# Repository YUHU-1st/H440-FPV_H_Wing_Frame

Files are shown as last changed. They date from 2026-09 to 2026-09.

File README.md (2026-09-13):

# H440 FPV H-Wing Tailsitter / H形尾座式垂起固定翼

> **B3：** [中框双向机械限位与 TPU 双端相机支撑 / Positively retained center decks and dual-ended TPU camera supports](H440_B3/README.md)。增加托板止挡肩、四根金属隔柱和上下相机固定点；机架预算约 659 g。28 种主零件、39 个装配实例，含更新的 STEP、碳板 DXF、SolidWorks 原生文件及双语说明。

> **B2 structural revision / B2 结构修订：** [开放电池托板、中央榫槽连接及加强机臂 / Open battery tray, bonded mortises and reinforced pylons](H440_B2/README.md). B2 STEP/DXF, comparative stiffness screening, and native SolidWorks save/reopen validation are complete. B2 的 STEP/DXF、刚度比较和 SolidWorks 原生保存/重开复核均已完成。下方 B1 内容保留为历史制造档案。

[中文说明](docs/README_zh-CN.md) · [English](docs/README_en.md) · [B1 validation / B1 复核](H440_B1/PR1复核报告.md) · [BOM](H440_B1/BOM与重量预算.md)

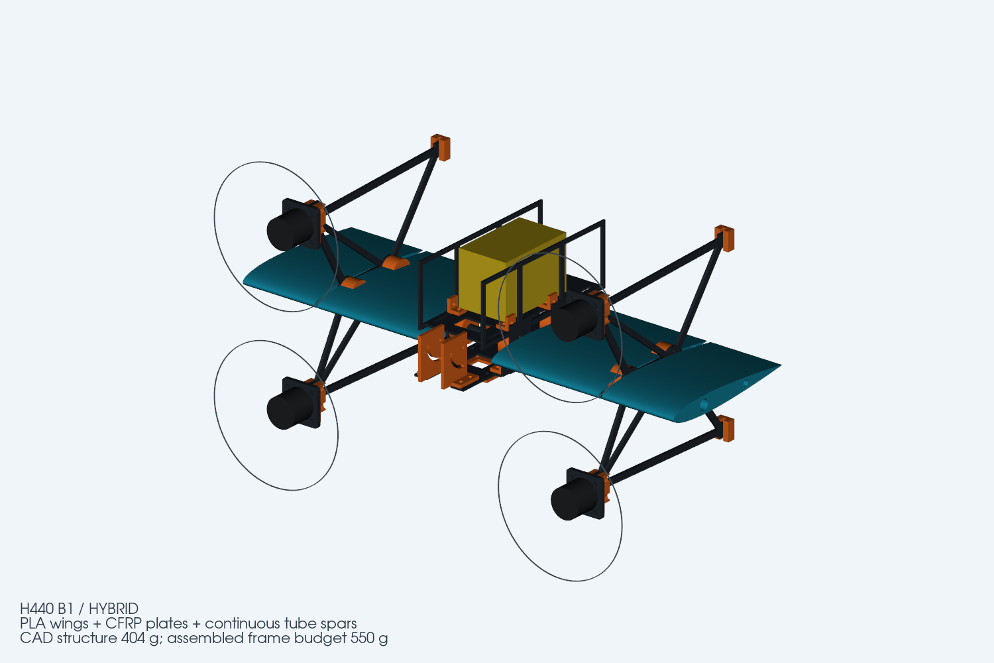
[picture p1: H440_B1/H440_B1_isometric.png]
H440 B1 isometric view


H440 is an engineering prototype for a compact, four-motor H-layout tailsitter VTOL airframe. The historical B1 manufacturing revision combines PLA printed wing shells, ABS fittings, 2–4 mm CFRP plates and continuous carbon-tube spars; the current B2 structural revision is documented separately above. It uses differential motor control without servos or aerodynamic control surfaces.

H440 是一款紧凑型四电机 H 形尾座式垂直起降固定翼工程样机。历史 B1 制造版本采用 PLA 打印机翼、ABS 连接件、2～4 mm 碳板和贯穿式碳管承力；当前 B2 结构修订见上方独立说明。整机构型通过四电机差速控制飞行，不使用舵机和气动舵面。

> **Prototype status / 样机状态：** CAD geometry, exports and native SolidWorks deliverables have been checked. Physical strength, propulsion, vibration, transition control and flight performance remain to be tested. / CAD 几何、导出文件和 SolidWorks 原生交付已检查；结构、动力、振动、转换控制和飞行性能仍需实物验证。

## Key specifications / 主要规格

| Item / 项目 | B1 |
| --- | --- |
| Configuration / 构型 | H-layout tailsitter VTOL / H形尾座垂起固定翼 |
| Wing / 机翼 | 440 mm span, 140 mm chord / 440 mm翼展、140 mm弦长 |
| Power / 动力 | 4 × 2306.5 1850 KV, 5-inch propellers / 四电机、5寸桨 |
| Flight stack / 飞塔 | 30.5 × 30.5 mm |
| Battery / 电池 | 6S 1600 mAh, sliding CG adjustment / 可前后移动配平 |
| Video / 图传 | Analog, DJI O4, DJI O4 Pro / 模拟、DJI O4、O4 Pro |
| O4 Pro camera / 相机 | M2 pivot + curved slots, 0–90° / M2枢轴＋弧形槽，0～90°连续可调 |
| Print bed / 打印平台 | Every printed part fits a 256 mm-class bed / 全部适配256 mm级平台 |
| Frame mass / 机架重量 | CAD 404.23 g; assembled budget 530.15 g; target reserve 550 g |

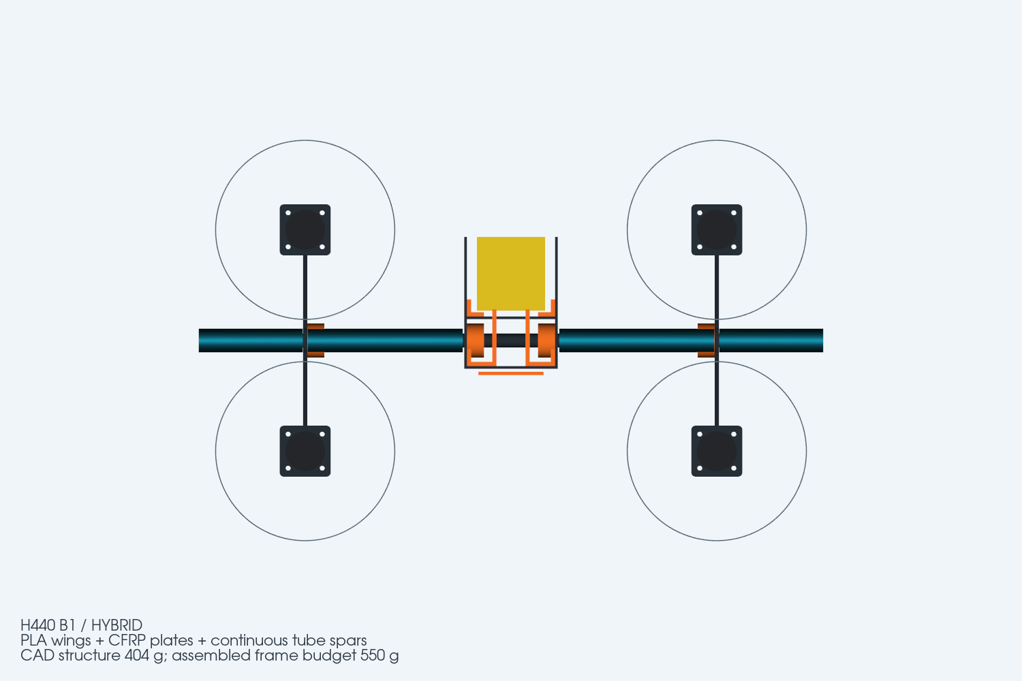
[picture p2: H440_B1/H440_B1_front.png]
H440 B1 front view


## Manufacturing downloads / 制造文件下载

| Package / 文件 | Contents / 内容 |
| --- | --- |
| [`H440_B1_supplier_DXF_STEP.zip`](H440_B1/H440_B1_supplier_DXF_STEP.zip) | 7 CFRP DXFs, matching STEP references and checksums / 7份碳板DXF、对应STEP和校验清单 |
| [`H440_B1_printed_parts_STEP.zip`](H440_B1/H440_B1_printed_parts_STEP.zip) | 19 printable STEP masters and checksums / 19个打印件STEP主模型和校验清单 |
| [`H440_B1_FRAME.SLDASM`](H440_B1/H440_B1_FRAME.SLDASM) | Native SolidWorks assembly / SolidWorks原生总装 |
| [`H440_B1_FRAME.step`](H440_B1/H440_B1_FRAME.step) | Named-part frame assembly / 带零件层级的机架总成 |
| [`H440_B1_LAYOUT.step`](H440_B1/H440_B1_LAYOUT.step) | Frame with equipment envelopes / 含设备参考包络的布局模型 |

DXF units are millimetres and contain final contours without cutter-radius compensation. Confirm kerf, sheet thickness, minimum internal radius and holding tabs with the supplier before cutting. STEP is the master format for printed parts; `_print.stl` files supply suggested orientation only.

DXF 单位为毫米，轮廓未包含刀具半径或切缝补偿。加工前应确认板厚、切缝、最小内圆角和夹持桥位。打印件以 STEP 为主模型，`_print.stl` 仅提供建议打印方向。

## Repository map / 仓库结构

```text
H440_B1/                       Active manufacturing revision / 当前制造版本
  C*.step + *_cut_mm.dxf       CFRP plate parts / 碳板零件
  P*.step + *_print.stl        Printed fittings and mounts / 打印连接件与设备座
  W*.step + *_print.stl        PLA wing sections / PLA机翼分段
  T*.step                      Carbon tubes / 碳管
  *.SLDPRT + *.SLDASM          Native SolidWorks delivery / SolidWorks原生文件
  SolidWorks_Assembly_Parts/   Persistent assembly instances / 装配实例
H440_A0/                       Archived design history / 历史版本
X120_A1/                       Small-scale experiment / 小比例实验
docs/                          Bilingual documentation / 中英文文档
build_h440_b1.py               Parametric geometry source / 参数化几何源
finish_h440_b1.py              Export and geometry checks / 导出与几何检查
```

## Rebuild / 重新生成

The editable source of truth is `build_h440_b1.py`. SolidWorks files are imported-body manufacturing deliverables rather than a hand-built parametric feature tree. / 可编辑几何以 `build_h440_b1.py` 为准；SolidWorks 文件是导入实体形式的制造交付。

```bash
python build_h440_b1.py
python finish_h440_b1.py
python package_h440_print_steps.py
python verify_delivery_archives.py
```

## Documentation / 文档

- [中文项目介绍与制造指南](docs/README_zh-CN.md)
- [English project overview and manufacturing guide](docs/README_en.md)
- [BOM 与重量预算](H440_B1/BOM与重量预算.md)
- [碳板供应商说明](H440_B1/供应商交付说明.md) · [CFRP supplier notes](H440_B1/CFRP_SUPPLIER_NOTES_EN.md)
- [打印件说明](H440_B1/打印件STEP交付说明.md) · [Printed STEP notes](H440_B1/PRINTED_STEP_NOTES_EN.md)
- [PR #1 复核报告](H440_B1/PR1复核报告.md)
- [详细设计与装配说明](H440_B1/设计与装配说明.md)

No flight-safety claim is made by this repository. Complete physical fit, load, vibration, propulsion and restrained-hover tests before flight. / 本仓库不对适飞性作出保证；飞行前必须完成装机、载荷、振动、动力和约束悬停测试。

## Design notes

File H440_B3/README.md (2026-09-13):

# H440 B3 — 中框机械限位与 TPU 双端摄像头支撑

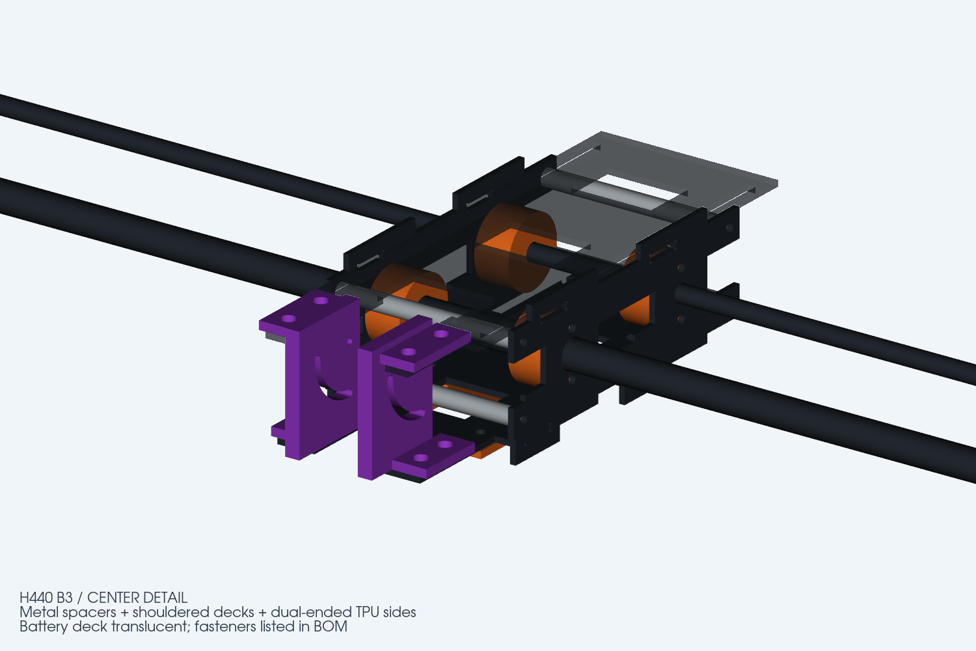
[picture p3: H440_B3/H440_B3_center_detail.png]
B3 中框与相机支撑 / Center-frame detail


本版针对 B2 中框榫舌左右防脱依赖胶接、TPU 摄像头侧板单端固定容易摆动的问题进行修改。翼展仍为 440 mm，机翼用 PLA，其余主连接件用 ABS；摄像头左右侧板用 TPU 95A。B3 中央板和相机支架须整套更换。

This revision adds positive lateral retention to the center frame and supports each TPU 95A camera side plate at both ends. The 440 mm wingspan, PLA wings and ABS structural fittings remain. Replace the center plates and camera supports as a complete B3 set.

## 中框如何限制左右滑动 / Lateral retention

飞控板四处榫根增加宽 20 mm 的止挡肩，12 mm 榫舌继续穿入侧板闭口槽。止挡肩贴合侧板内表面；电池板原有 62 mm 宽主体同样形成止挡。四根 OD6/ID3.3×62 mm 铝合金隔柱加 M3 贯穿螺栓固定两侧板间距，前后孔距 102 mm、上下孔距 24 mm。两侧板不能自由张开，托板不能越过止挡肩横移。没有角码。

Four 20 mm-wide shoulders on the electronics deck stop against the side-plate inner faces; 12 mm tongues enter the closed mortises. The 62 mm battery deck also provides shoulders. Four OD6/ID3.3×62 mm aluminium spacers and through-bolts lock the side-plate spacing, on a 102×24 mm pattern. No angle brackets are used.

榫槽仍有加工装配间隙，胶接用于消除上下、前后微动和提高抗扭刚度；不能把有游隙的干装件当成无振动结构。先干装核对四根隔柱等长、肩部贴合和托板平行，再薄层胶接，按实际板厚修整榫槽，禁止用螺栓强行拉弯碳板。

The mortises retain manufacturing clearance. Bond after dry-fitting to remove vertical/longitudinal micro-movement and improve torsional stiffness. Match spacer lengths, seat the shoulders and keep the decks parallel; do not pull warped or oversized parts into place with bolt preload.

## 摄像头支撑 / Camera support

两块 TPU 侧板由 3 mm 改为 5 mm，每块下端两颗 M3 固定在飞控板，上端两颗 M3 固定在电池板新增的前伸支耳。共八个固定点，每个 3 mm 厚固定脚配 OD5/ID3.2 限压套和大垫片。上固定脚在电池板上面，避开 M2 调角头部；电池板中央前缘开口避让相机接近朝下时的后上角。保留 M2 枢轴和弧槽连续 0–90° 调节。

Each 5 mm TPU plate uses two lower M3 screws on the electronics deck and two upper M3 screws on the extended battery-deck tabs. Eight metal crush sleeves and broad washers control compression. The upper feet sit above the battery deck, clear of the M2 adjustment screws. A center-front cutout clears the camera near its downward position. The M2 pivot and curved slot retain continuous 0–90° adjustment.

TPU 不是刚性材料，双端固定缩短自由弯曲段、减少摆动，但不能保证图像无抖动。使用 95A、侧板和固定脚高实心度打印；M2 外侧加金属垫片，按实际堆叠选螺钉长度，摄像头螺纹拧入长度不超过既定 2 mm 限值。锁角后要检查温升和时间造成的角度松动。95A 产品数据可参考 [Polymaker TPU95](https://wiki.polymaker.com/polymaker-products/more-about-our-products/documents/technical-data-sheets/tpu/polyflex-tm-tpu95)，不能直接当作实际打印件的力学证书。

TPU remains compliant. Dual support reduces unsupported bending length but does not guarantee vibration-free video. Print 95A with dense walls/feet, use metal washers on the M2 adjustments and select screw length for the actual stack and camera thread-engagement limit. Check angle retention after warming and dwell time.

## 验证与交付 / Checks and files

机架估计 659.2 g，较 B2 增加约 55.2 g；建议按 680 g 预留，尚未切片或实物称重。四根铝隔柱用标准管料定尺切断，新增成本主要为隔柱和普通螺钉。

Estimated frame mass is 659.2 g, approximately 55.2 g above B2; reserve 680 g pending slicing and weighing. Standard cut-to-length spacer stock and ordinary fasteners keep the added hardware simple.

- [BOM 与重量预算](BOM与重量预算.md)
- [中框结构复核](中框结构复核.md)
- [总装 STEP](H440_B3_FRAME.step) · [SLDASM](H440_B3_FRAME.SLDASM)
- [碳板 DXF/STEP 加工包](H440_B3_supplier_DXF_STEP.zip)
- [全部打印件 STEP 包](H440_B3_printed_parts_STEP.zip)
- [几何检查](geometry_report.json) · [机械限位与螺钉空间检查](B3_specific_checks.json)
- [原生保存与重开报告](solidworks_native_report.json)

几何检查包含全部实体干涉、±30 mm 电池配平空间、0–90° 相机本体及光轴扫掠、贯穿螺栓与头部空间、限压套和 M2 垫片空间。原生文件为导入实体，修改主尺寸应重新生成源模型；原生重开记录不代表实物强度或模态验证。

Checks cover solid intersections, battery travel, camera body/optical-axis sweep, through-bolt/head paths, crush sleeves and M2 washer clearance. Native files contain imported solids. Regenerate the source geometry for dimension changes; successful reopening is not physical strength or modal validation.

28 个原生主零件已逐个重开并核对实体数量和体积；总装 39 个组件引用全部有效，复开错误为 0。强制重建并保存后仍有 SolidWorks `NeedsRegen` 警告码 32，接收方应在其环境中重建并核对模型；这不等于整机强度已通过测试。

All 28 native masters were reopened and checked for solid count and volume. The 39-component assembly has no missing references or load errors. SolidWorks still reports `NeedsRegen` warning 32 after rebuild/save; rebuild and inspect in the recipient environment. This is not physical structural validation.

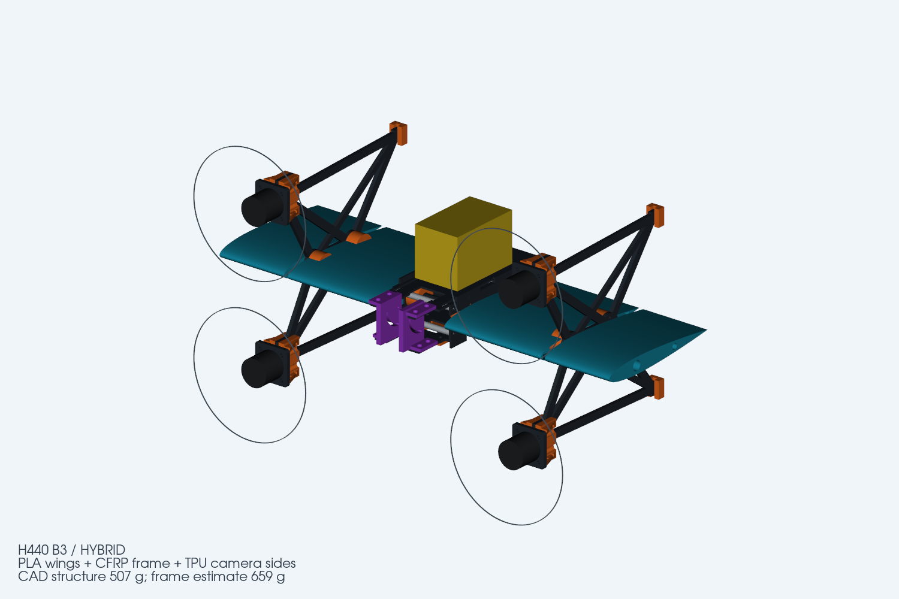
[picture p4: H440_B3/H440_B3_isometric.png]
B3 总装 / Assembly


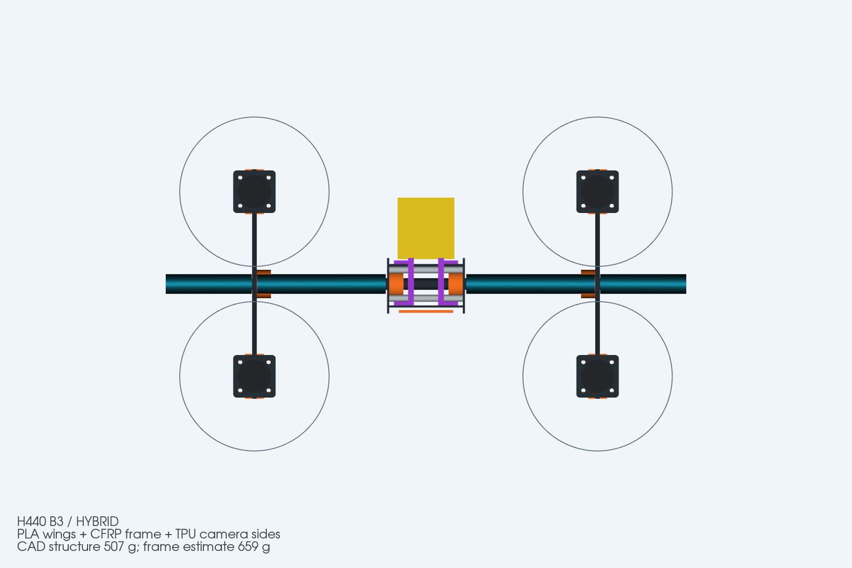
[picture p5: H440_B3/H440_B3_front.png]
B3 正视 / Front


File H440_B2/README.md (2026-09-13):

# H440 B2 — 开放电池托板与加强机臂 / Open battery tray and reinforced pylons

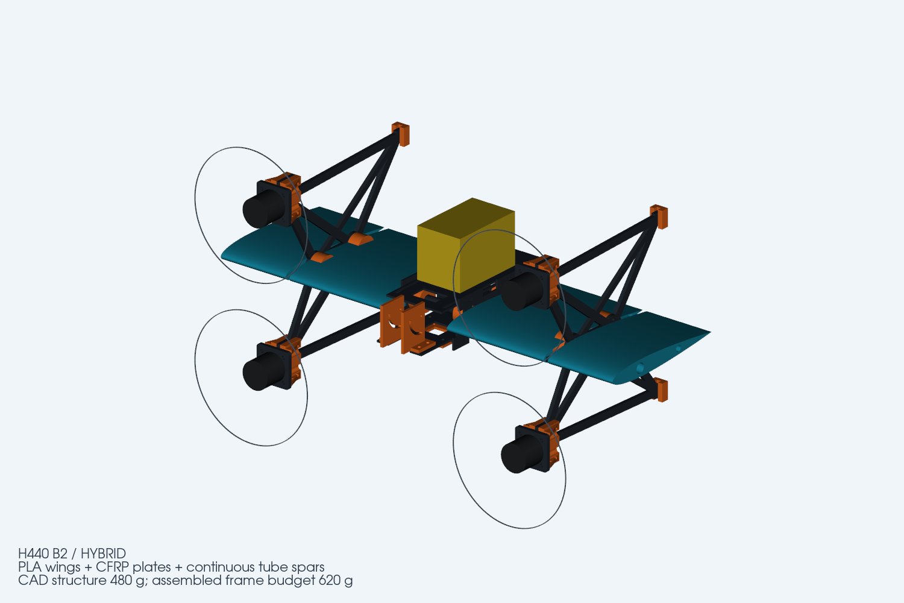
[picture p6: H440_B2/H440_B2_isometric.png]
B2 isometric


本版取消电池侧围板和中央 8 个打印角码，中央碳板改用一体榫舌＋闭口榫槽胶接。左右机臂升级为 4 mm 交叉加强碳板，四个电机 U座采用四孔夹紧和三角筋。B1 保留为历史制造版本；B2 不与 B1 零件混装。

This revision removes the battery cage and eight printed center-frame angles. Integral CFRP tongues fit bonded closed mortises. Both pylons use 4 mm CFRP with cross-bracing; all four motor clevises gain four-point clamping and triangular ribs. B1 remains the historical manufacturing revision. Do not mix B1 and B2 parts.

## 文件状态 / Delivery status

- 当前几何源：`../build_h440_b2.py`；27 种零件、35 个装配实体、18 个打印件 STEP、7 种碳板 DXF。
- Current geometry: 27 part definitions, 35 frame instances, 18 printable STEP files, seven CFRP DXF profiles.
- [碳板 DXF＋STEP 包 / CFRP package](H440_B2_supplier_DXF_STEP.zip)
- [打印件 STEP 包 / Printed parts](H440_B2_printed_parts_STEP.zip)
- [总装 STEP / Assembly STEP](H440_B2_FRAME.step)
- [SolidWorks 原生总装 / Native SolidWorks assembly](H440_B2_FRAME.SLDASM)
- `*.SLDPRT`：27 种 B2 原生零件；`SolidWorks_Assembly_Parts/`：总装使用的持久化实例文件。
- [SolidWorks 原生保存/重开报告 / Native save/reopen report](solidworks_native_report.json)
- [结构复核与装配要求 / Structural screening and assembly notes](结构复核与装配要求.md)
- [BOM 与重量预算](BOM与重量预算.md)
- **B2 SolidWorks 原生交付已完成验证。** 27 种原生零件均在 SolidWorks 2024 SP0.1 中静默重开通过；总装包含 35 个生成实例，重开错误为 0，所有组件引用均落在 `H440_B2/` 交付目录内。重建并保存后已消除内部 ID 不匹配警告，复开仍返回“需要重建”警告码 32；制造前应在接收方 SolidWorks 环境中执行一次强制重建并另存。STEP 导入在本机表现为扁平化 35 零件树，脚本同时兼容带根包装总成的导入形态。
- **B2 native SolidWorks delivery is verified.** All 27 native part files reopen in SolidWorks 2024 SP0.1. The assembly contains 35 generated instances, reopens with zero load errors, and every component reference resolves inside the `H440_B2/` delivery directory. Rebuild/save cleared the internal-ID mismatch warning; reopening still returns the `NeedsRegen` warning bit 32, so force-rebuild and save once in the recipient's SolidWorks environment before manufacturing. The local STEP import resolves as a flattened 35-part tree; the delivery script also supports a wrapper-subassembly import shape.

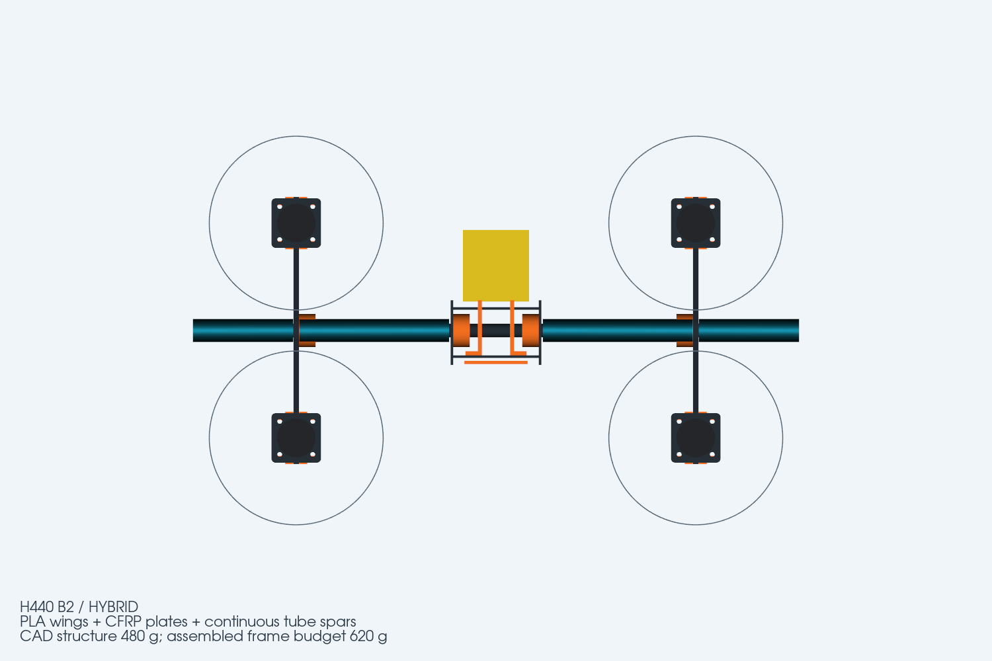
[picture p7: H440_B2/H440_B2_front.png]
B2 front


## 重量与刚度 / Mass and stiffness

机架 CAD 结构约 479.61 g，含五金、绑带、胶和金属配合垫片的机架预算约 604.01 g；建议按 620 g 预留。相对 B1 的 530.15 g 增加约 73.86 g。质量仍是体积/采购预算估算，需切片和装机称重。

CAD structure is approximately 479.61 g; assembled-frame estimate is 604.01 g, with a 620 g planning allowance. This is about 73.86 g above B1. These are estimates, not measured masses.

同一固定根部梁模型下，每电机 3 N 侧向载荷对应位移由 1.033 mm 降至 0.281 mm；0.15 N·m 反扭矩工况的转角由 0.897° 降至 0.251°。这些是理想机臂骨架的对比结果，不含打印件、胶接、管梁和螺栓连接柔度，不代表整机有限元或模态验证。

In the same fixed-root beam model, a 3 N lateral load per motor produces 1.033 mm displacement in B1 versus 0.281 mm in B2. Under the assumed 0.15 N·m motor-torque case, rotation drops from 0.897° to 0.251°. These are ideal pylon-skeleton comparisons, excluding printed fittings, adhesive, spars and joint compliance; they are not complete-aircraft FEA or modal validation.

## 首件要求 / First article

榫槽名义 2.2 × 12.2 mm，榫舌 2 × 12 mm；按实际碳板厚度和铣刀调整后先试拼，胶接防退出。电机夹槽为 4.15 mm，使用硬质金属垫片消除与实测 4 mm 碳板的间隙，禁止用软泡棉或过度拧紧 ABS 来补间隙。仍须完成胶接、静载、温升蠕变、振动和无桨控制方向检查。

Nominal mortises are 2.2 × 12.2 mm for 2 × 12 mm tongues. Adjust to measured laminate thickness and cutter capability, dry-fit, then bond for retention. The motor-clevis gap is 4.15 mm; use hard shims to fit the actual 4 mm plate. Do not use foam or excessive tightening of ABS to remove clearance. Bond, static-load, thermal-creep, vibration and propeller-off control checks remain necessary.

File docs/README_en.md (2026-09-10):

# H440 B1 Project Overview

[Home](../README.md) · [中文](README_zh-CN.md)

H440 B1 isometric view

## Objective

H440 B1 is a 440 mm-span H-layout tailsitter VTOL frame designed around four 2306.5 1850 KV motors and 5-inch propellers. All attitude control is intended to come from differential motor thrust; the airframe has no servos or aerodynamic control surfaces.

The design prioritizes compact proportions, common FPV electronics and fabrication on a 256 mm-class printer. Its wing is divided into four PLA sections, the structural fittings are ABS, and the primary motor loads pass through 2–4 mm CFRP plates and two continuous carbon-tube spars.

## Structure

- A 10/8 × 420 mm main tube and a 6/4 × 420 mm rear tube run continuously through both wings and the center frame.
- The center sides and floors use 2 mm CFRP; motor trusses use 3 mm CFRP; motor plates use 4 mm CFRP.
- The load path is motor → 4 mm motor plate → ABS clevis → 3 mm truss → bonded collar → continuous tubes → center frame.
- Calculated CAD structure mass is 404.23 g. The assembled-frame budget is 530.15 g; use 550 g as the first-article target.

H440 B1 front layout

## Electronics and camera

- The FC/ESC stack pattern is 30.5 × 30.5 mm. The stack and video transmitter may remain exposed for passive cooling.
- Interchangeable plates support analog video, DJI O4 and DJI O4 Pro.
- The O4 Pro camera uses independent ABS side brackets. Each side has one M2 pivot and one M2 fastener in an R16 curved slot, giving continuous manual adjustment from forward-facing to straight-down, 0–90°.
- A 361-position sweep at 0.25° increments found no camera, bracket, deck or optical-axis collision; minimum deck clearance was approximately 2.128 mm.
- Nominal bracket clear width is 20.4 mm. With a 20 mm camera body, about 0.2 mm remains per side; make a fit coupon and compensate for measured ABS shrinkage.
- Camera-thread engagement must not exceed 2 mm. Select screw length after accounting for the bracket and washers.
- A 20 mm two-hole interface is reserved for a future single-axis servo gimbal; the complete gimbal is outside the current delivery.

## Battery and CG

Two 132 × 3 mm longitudinal slots let two 20 mm hook-and-loop straps move with the battery. The current CAD check uses a 78 × 48 × 52 mm envelope for the target 6S 1600 mAh pack and found no frame collision at forward, center and rear positions.

Measure the actual pack before production. The 148 mm tray provides 70 mm total travel; approximately ±30 mm is the recommended working range.

## Manufacturing files

- [`H440_B1_supplier_DXF_STEP.zip`](../H440_B1/H440_B1_supplier_DXF_STEP.zip): seven CFRP DXFs, seven matching STEP references, notes and SHA-256 manifest.
- [`H440_B1_printed_parts_STEP.zip`](../H440_B1/H440_B1_printed_parts_STEP.zip): 19 printable STEP masters—15 fittings/mounts and four wing sections.
- [`H440_B1_FRAME.SLDASM`](../H440_B1/H440_B1_FRAME.SLDASM): native SolidWorks 2024 assembly.
- [`H440_B1_FRAME.step`](../H440_B1/H440_B1_FRAME.step): neutral frame assembly with named parts.
- [`H440_B1_LAYOUT.step`](../H440_B1/H440_B1_LAYOUT.step): frame plus equipment envelopes for layout checks only.

Use the DXFs as the CFRP cutting definition. Units are millimetres and cutter compensation is not included. STEP is the printed-part master; STL only supplies a suggested orientation.

## Digital validation

- Every STEP passed a read-back check; all seven DXFs declare millimetre units.
- Frame solid-interference count is zero; the O4 Pro 0–90° sweep reports zero collisions.
- All 28 master SLDPRTs were saved and reopened; 43 assembly-instance SLDPRTs have persistent repository paths.
- Both archives passed CRC, internal SHA-256, expected-count and byte-for-byte disk-master checks.

## First-article sequence

1. Measure the actual battery, motors, stack, video unit and camera.
2. Print wing-skin/tube-sleeve, insert-hole and O4 Pro bracket coupons first.
3. Pull/torsion-test bonded tubes and pull-test heat-set inserts using production materials.
4. Complete propeller-off direction, thrust/current/temperature and vibration checks.
5. Weigh installed components and calculate the three-axis center of gravity.
6. Complete static-load and restrained-hover testing before flight and transition tuning.

This revision is a digitally checked engineering prototype, not a flight-qualified product.

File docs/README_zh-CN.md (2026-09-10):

# H440 B1 中文项目介绍

[返回主页](../README.md) · [English](README_en.md)

H440 B1 等轴测视图

## 项目目标

H440 B1 是翼展 440 mm 的 H 形尾座式垂直起降固定翼机架，目标动力为四颗 2306.5 1850 KV 电机配 5 寸桨。飞行姿态全部依靠四电机差速控制，不设置舵机和气动舵面。

本设计强调紧凑比例、常见穿越机电装兼容性和小型打印机可制造性。机翼拆成四段 PLA 打印件，结构连接件使用 ABS，电机载荷通过 2、3、4 mm 碳板和两根贯穿式碳管传递。所有打印件均适配 256 mm 级打印平台。

## 结构方案

- 四段 PLA 打印翼壳负责气动外形，并通过管套与碳管连接。
- 10/8 × 420 mm 主碳管和 6/4 × 420 mm 后碳管整根贯穿机翼与中央框。
- 中央侧板、电池板和电子板使用 2 mm 碳板；电机桁架使用 3 mm 碳板；电机板使用 4 mm 碳板。
- 承力路径为：电机 → 4 mm 电机板 → ABS U形座 → 3 mm 桁架 → 梁套 → 贯穿碳管 → 中央框。
- 机架 CAD 结构质量约 404.23 g；计入五金、绑带、泡棉和胶后预算约 530.15 g，建议按 550 g 控制首件机架重量。

H440 B1 正视布局

## 电装与相机兼容

- 飞塔采用 30.5 × 30.5 mm 孔距，并允许飞控、电调和图传外露散热。
- 可换板覆盖模拟图传、DJI O4 和 DJI O4 Pro。
- O4 Pro 摄像头使用左右独立 ABS 侧板。每侧一颗 M2 螺钉作枢轴，另一颗沿 R16 圆弧槽锁紧，可在朝前至朝下的 0～90° 范围连续手调。
- CAD 按 0.25° 步长检查 361 个相机姿态，未发现侧板、底板或光轴干涉，最小底板间隙约 2.128 mm。
- 侧板名义内净宽 20.4 mm，相对 20 mm 相机宽度每侧仅余约 0.2 mm；首次打印应做局部样件并补偿 ABS 收缩。
- 相机侧螺纹最大旋入深度为 2 mm，应结合垫片和侧板厚度选择 M2 螺钉。
- 保留单轴舵机云台 20 mm 双孔接口；当前交付不包含完整云台机构。

## 电池与重心

电池板设两条 132 × 3 mm 纵向穿带槽，两条 20 mm 魔术贴绑带可与电池共同前后移动。CAD 暂按 78 × 48 × 52 mm 的 6S 1600 mAh 电池包络检查，前、中、后三个位置均无机架干涉。

批量加工前应实测电池。148 mm 托板提供 70 mm 总几何行程，建议有效配平范围约为 ±30 mm，并在端部保留余量。

## 制造文件

- [`H440_B1_supplier_DXF_STEP.zip`](../H440_B1/H440_B1_supplier_DXF_STEP.zip)：7 份碳板 DXF、7 个同名 STEP、说明和 SHA-256 清单。
- [`H440_B1_printed_parts_STEP.zip`](../H440_B1/H440_B1_printed_parts_STEP.zip)：15 个连接件/设备座和 4 个 PLA 机翼分段，共 19 个 STEP。
- [`H440_B1_FRAME.SLDASM`](../H440_B1/H440_B1_FRAME.SLDASM)：SolidWorks 2024 原生总装。
- [`H440_B1_FRAME.step`](../H440_B1/H440_B1_FRAME.step)：保留零件层级的通用机架总成。
- [`H440_B1_LAYOUT.step`](../H440_B1/H440_B1_LAYOUT.step)：含设备参考包络，仅供布局检查。

碳板下料以 DXF 为准，单位为毫米，轮廓未做刀具补偿。打印件以 STEP 为主模型，STL 只给出建议打印方向。详细数量、材料和五金见[完整 BOM](../H440_B1/BOM与重量预算.md)。

## 数字验证状态

- 所有 STEP 通过重新读取检查；7 份 DXF 均为毫米单位。
- B1 实体干涉数为 0；O4 Pro 相机 0～90° 扫掠碰撞数为 0。
- 28 个主 SLDPRT 已保存并重新打开；43 个装配实例 SLDPRT 已持久化到仓库路径。
- 两个交付压缩包通过 CRC、内部 SHA-256、文件数量和磁盘主模型一致性检查。

## 首件验证顺序

1. 实测电池、电机、飞塔、图传和相机尺寸。
2. 先打印翼皮/管套、热熔嵌件孔和 O4 Pro 侧板小样。
3. 用生产材料制作碳管胶接和嵌件拉拔试样。
4. 完成无桨方向、推力/电流/温升和振动检查。
5. 称量实际部件并计算三轴重心。
6. 完成静载与约束悬停后，再进行低风险飞行和转换调试。

当前版本是经过数字制造检查的工程样机，不等同于已经验证的适航产品。

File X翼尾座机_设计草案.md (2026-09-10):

# X翼尾座式微型飞机：参数草案 A0

状态：概念和重量预算，不是已经验证可飞或可直接打印的定型设计。用户尚未确认X翼定义、电机KV/孔位、Air65具体版本、打印机及喷嘴。未生成或验证SolidWorks原生零件。

## 构型

四电机固定轴向推力，尾座起降，机体整体转向进入前飞；前视四片翼以45°交叉呈X。不增设倾转机构和舵机，依靠四电机差动及反扭矩控制。前飞滚转控制依赖电机反扭矩，控制余量需单独验证，不能由悬停成功推断前飞可控。沿用电装不等于可直接沿用原厂PID、模式、混控和安装方向。

初始几何用于布局比较：机体纵向为X，前进为+X；四翼沿YZ平面45/135/225/315度方向展开。中心体半径约18 mm；每片外露径向展长95 mm、弦长45 mm；翼尖水平/垂直总包络约160 mm（2×113/√2）。四片总外露面积171 cm²。电机中心径向距离建议先取55 mm，相邻中心距离77.8 mm，给31 mm桨留出充分平面间隙；桨盘轴向置于翼前缘前方，实际间距必须按电机高度、桨挠度及螺钉设计。不能把桨盘画在翼面内。

四片45度翼并非171 cm²水平机翼：小迎角线性近似下，垂向升力贡献按cos²45°折算，有效面积约85.5 cm²；干扰、机身遮挡、低雷诺数和失速均未计入。若总重30 g、假定有效CL=0.5，则估算平飞速度约10.6 m/s，弦长雷诺数约3.2万。该CL是计算假设，必须通过试验或低雷诺数气动分析验证，不能据此给出保证失速速度。

翼面采用0.20–0.24 mm打印薄板，根部及局部翼梁加厚；先以对称薄平板试样验证，不虚构已优化翼型。全表面积0.20 mm PLA薄板理论质量4.24 g（密度1.24 g/cm³）。ABS按1.04为3.56 g，ASA按1.07为3.66 g，均不含加强筋及接缝；密度以耗材数据为准。薄板抗扭刚度很低，必须补足加强结构并核验颤振/变形。

## 电装接口

- Air65原版机架官方飞控孔距26×26 mm；Air65 II/Champion机架标称25.5×25.5 mm。待确认实物后固定一种孔距和方向，不直接以板外形代替孔位。
- BETAFPV原版机架电机接口为3-M1.4、6.6 mm孔位标称；这不是百达0702孔位已确认的证据。必须实测螺孔分布、中心避空、出线方向、轴径、轴伸和电机底部尺寸，采用可替换电机座。
- C03原版摄像头官方外廓11×14.1×13.5 mm，夹持间隙先留每侧0.15–0.25 mm，用小样校准；原装罩若可复用应先称重比较。镜头方向按前飞视野设计，悬停时视野明显变化。
- 飞控软安装，底面器件、天线、电池和电机线均留空间；孔径按实际胶钉/减震胶圈设计，不能把M1.4电机孔复制成飞控孔。
- 1S电池沿机身纵向可移动固定，先称重测尺寸再建卡槽；不要只按容量推断外形。机翼初始重心探索区在前缘后20–25%弦长（9–11.25 mm），仅为试验起点，尚未确定中性点及静稳定裕度。

## 质量与动力验收

打印结构目标8–10 g（包含翼面、加强筋、中心机身、电机座和尾撑），不是CAD或切片实测结果。总重必须逐项相加：四电机、四桨、完整电装与天线线材、电池、打印件、螺钉胶圈和胶水。目标总重约28–32 g需实物预算支持，否则缩减结构或重新论证。

在计划使用的百达电机、KV、1.2寸具体桨型和电池上测单电机静推力、电流和温升；再测完整机体，核验翼面遮挡和电压跌落。设计验收目标可先设最低工作电压下总推重比≥1.8（不是充分飞行保证）；若总重30 g，四电机合计至少54 gf，平均每电机13.5 gf。同时不得超过实物ESC、接插件和电池持续电流能力。没有这些数据不能保证起飞、续航或转换。

Betaflight原厂Air65配置是四旋翼配置。研究样机可探索机体系角速度控制，但ANGLE自稳参考不能直接同时满足尾座悬停和水平前飞。需验证安装方向、差动响应、前飞滚转权限和转换控制；不提供未经验证的可直接粘贴CLI。若要求自动转换和两种姿态自稳，必须单独解决兼容固件/控制器方案。

## 初始打印参数（试样起点，不是已验证机器配置）

建议0.2 mm喷嘴用于此尺寸薄壁件；如只有0.4 mm喷嘴，需重新调整筋宽和孔周尺寸，而不是机械套用。

| 参数 | PLA | ABS | ASA |
|---|---|---|---|
| 喷嘴温度 | 205–220℃ | 240–255℃ | 245–260℃ |
| 热床 | 50–60℃ | 95–105℃ | 95–110℃ |
| 层高 | 0.10 mm | 0.10 mm | 0.10 mm |
| 初始线宽（0.2喷嘴） | 0.22–0.24 mm | 0.22–0.24 mm | 0.22–0.24 mm |
| 外壁速度 | 20–30 mm/s | 20–30 mm/s | 20–30 mm/s |
| 风扇 | 首层低风，后续70–100% | 0–15% | 0–20% |
| 环境 | 避免高温软化 | 封闭腔体并排风 | 封闭腔体并排风 |

以耗材厂商温度范围及打印机热端/喷嘴兼容要求优先。四翼分别平放，0.20 mm膜面由两层0.10 mm实体层组成；首层也必须0.10 mm，否则总厚度改变。不能给这种两层翼面设置0顶层/0底层并期待得到封闭膜面。筋宽至少两条校准线宽，孔周约0.8–1.0 mm起步；电机座和翼根做局部实体，而空腔区域用几何镂空减重。结构件2道壁起步、按局部受力加厚，避免用全局高填充掩盖设计问题。无需全机支撑，接口若需要支撑应改分件/方向。

先打印含电机孔、飞控安装孔和薄翼根的接口小样。孔径补偿先取0，以试样实测校正；不要统一夸大孔径。ABS/ASA收缩和翘曲尤其可能使小螺孔及0.2 mm膜面失真。薄翼按需要加3–5 mm可剥离边，去除边料后称重。不得强行装入过长电机螺钉，按螺纹有效深度和座厚选长度。

## 下一版完成条件

1. 确认尾座式X翼定义、电机商品型号/KV、实物接口、Air65版本、打印机及喷嘴。
2. 建立参数化中心体、可替换电机座、四片翼、相机座、电池夹和尾撑；先做装配包络与桨盘碰撞检查。
3. 计算CAD体积、按材料估质量、实际切片，若超8–10 g结构目标则重新设计；不能仅报目标重量。
4. 输出SLDPRT/SLDASM与分件STL，核验孔位和薄壁工具路径；当前版本尚无这些文件。
5. 无桨验证控制方向，再测台架推力，继而进行约束悬停和渐进转换试验。未经这些步骤不标注“可飞”。

## 官方参考

- https://betafpv.com/products/air65-brushless-whoop-frame
- https://betafpv.com/products/air65-champion-brushless-whoop-frame
- https://betafpv.com/products/air65-brushless-whoop-quadcopter
- https://betafpv.com/products/c03-fpv-micro-camera
- https://betaflight.com/docs/wiki/guides/current/Modes

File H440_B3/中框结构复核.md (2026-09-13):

# B3 中框结构复核与实物验收

## 已解决的约束缺口

B2 的飞控板主体宽 50 mm，榫舌根部没有贴住侧板内面的宽肩。单纯把侧板间距锁住，仍不能阻止该托板沿 X 横移退出另一侧榫槽。B3 在四个榫根添加宽 20 mm、末端到 X=±31 mm 的肩部；四根隔柱固定侧板内距 62 mm。正负 X 各移动 0.1 mm 的几何测试应与侧板产生实体交叠，证明肩部提供双向几何止挡；这是约束检查，不是承载证明。

电池托板主体宽 62 mm，已有双向肩部。中央上、下榫槽仍分别限制 Y 上下和 Z 前后运动。贯穿螺栓、隔柱及肩部承担防张开、防退出约束；配合胶缝消除槽内微动。四根隔柱位于 Y=±12、Z=-20/-122 mm。前上紧固件已与机翼前缘检查避让。

## 受力与变形判断

所有结构受载都会变形。B3 的限位比 B2 明确，但未取得实际碳板铺层、胶接强度、螺栓预紧、TPU 小应变/温度特性和整机实测载荷，不能给出“不会变形”或整机强度已认证的结论。

四根金属隔柱限制两侧板相向压缩，贯穿螺栓限制向外张开，四处托板肩部传递横向力；上下托板和侧板通过胶接榫槽闭合抗扭受力路径。隔柱只解决侧板间距与横向锁紧，不能单独代替榫槽胶接的抗剪和抗扭作用。碳板肩根、槽端、侧板长条和螺栓孔仍是需观察的应力集中区域。

若仅估算隔柱轴向弹性，以铝 E=69 GPa、OD6/ID3.3、L=62 mm 假设，单根 EA/L 约 21.9 kN/mm，四根共同承担 10 N 时理想轴向缩短约 0.00011 mm。这不包括板件弯曲、接触间隙、螺栓和胶缝变形，不可用作整机刚度或安全系数。实际可见晃动更可能来自接头间隙、碳板弯曲或 TPU，而非隔柱轴向压缩。

TPU 上下各两个固定点限制侧板整体摆动和转动，5 mm 壁厚增加弯曲刚度。弧槽削弱局部截面，TPU 会蠕变；没有经过超弹性分析、预紧接触分析或振动试验，因此不报告虚构的整机固有频率、疲劳寿命或“防震荡百分比”。

## 首件验收

1. 测量四根隔柱长度和碳板厚度。62 mm 为名义隔距，以肩部真实宽度协调配合，四柱等长，所有肩部应自然贴合；不可压弯板件来补尺寸。
2. 干装后用小载荷在飞控板上左右推拉，观察肩部是否离缝、榫舌是否窜动，再完成胶接固化。螺栓以垫片压在碳板上、螺母可靠防松为准，扭矩由实物压溃与供应商建议确定。
3. TPU 固定脚使用 3 mm 名义限压套；实际套长与打印脚厚相配，端面不能明显高出而使 TPU 悬空，也不能过短导致压瘪。M2 调角处配硬垫片并检查夹持后角度保持。
4. 先以手持测力计作小幅左右、上下加载并记录卸载回零，再按实际设备质量和飞行加速度确定验收载荷。热机后重复测量，检查 TPU 蠕变、胶缝开裂、肩根损伤和螺栓松动。
5. 装机后进行无桨转速扫描与陀螺仪/视频振动记录；上桨须在隔离台架上进行。机械游隙或持续增大的变形必须先处理，不能靠滤波或 PID 掩盖。

## English summary

B3 adds positive shoulders at all four electronics-deck tongues and four metal spacers/through-bolts that lock the side-plate spacing. Bonding still removes mortise clearance and contributes shear/torsional stiffness. The dual-ended 5 mm TPU camera plates reduce unsupported motion, with crush sleeves controlling M3-foot compression. These are constraint and geometry improvements; full-airframe strength, joint preload, creep and vibration remain physical-validation items.

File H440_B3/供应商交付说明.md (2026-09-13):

# H440 B3 碳板加工说明

单位 mm，DXF 为 1:1 平面闭合轮廓。STEP 用于检查实体厚度和孔位。只加工 C 开头的七种碳板：C01/C02/C03/C04 为 2 mm，各一件；C05/C06 为 4 mm，各一件；C07 为 4 mm，四件。材料为含 0/90 和 ±45 铺层的实碳板，具体材料证书由供应商提供。

C01/C02 增加四个横向贯穿螺栓孔；C04 榫根有宽肩限位，禁止擅自削窄。C03 前伸支耳配合 TPU 上固定脚，中央前缘让位口不得填回。B3 中央四块板配套加工，不与 B2 混装。

榫舌名义 2×12，榫槽 2.2×12.2，槽角 R0.6 退刀适合最大 Ø1.2 刀具。按实测厚度、刀径和实际刀缝协调配合，先做榫槽试片；不得把所有孔槽自动放大或缩小。所有孔为通孔，无沉头。板边去毛刺，不破坏肩根和槽边。加工前供应商核对 DXF 闭合、刀具可达性和公差。

四根横向隔柱另采购/切断：铝合金 OD6、ID3.3、名义长度 62，四根等长，端面平整；以实际托板肩宽和试拼尺寸协调。它们不是碳板，也不由本包的 DXF 加工。打印件见独立 STEP 包。

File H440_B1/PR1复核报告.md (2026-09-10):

# H440 B1 — PR #1 复核报告

复核日期：2026-09-11
当前 Git 提交：`70ecfbf07fc719eefa166992cb021f73c9a33cc3`（包含 PR #1）

## 结论

PR #1 的方案比原 B1 更符合需求，可以进入首件加工和装机试配。它补齐了 DJI O4 Pro 摄像头独立左右侧板、M2 枢轴孔与 0～90° 圆弧锁紧槽，也改善了天空端区域的被动散热开口。CAD 检查没有发现阻止首件制造的干涉或缺失文件。

此结论只覆盖 CAD 完整性、几何干涉和制造文件一致性。机架仍需实物试装、静载/振动试验、动力系统测试、实际称重与重心复核后才能判断是否适飞。

## 复核结果

- O4 Pro 摄像头外形按 25.55 × 20 × 23.3 mm 建模；侧面使用 M2 螺钉，枢轴至圆弧槽中心线半径 16 mm。
- 左右相机侧板提供 0～90° 连续手动调角范围，可覆盖朝前至朝下；以 0.25° 步长检查 361 个姿态，未发现相机与侧板、电子舱底板或光轴通道碰撞。
- 全角度范围内最小底板间隙为 2.128 mm。
- O4 Pro 两侧板名义内净宽 20.4 mm。相对 20 mm 相机宽度每侧只有约 0.2 mm 余量，因此首次打印应先做局部试装，并按 ABS 实际收缩与打印机孔补偿调整。
- 电池包络在前、中、后三个配平位置的干涉数均为 0。
- 7 个碳板 DXF 均使用毫米单位；对应 7 个碳板 STEP 与当前磁盘主文件逐字节一致。
- 打印件包包含 19 个 STEP：15 个 `P*.step` 连接件/设备安装件和 4 个 `W*.step` PLA 机翼分段。
- 28 个主零件 SLDPRT 和 43 个装配实例 SLDPRT 均存在且非空。原生交付报告记录 28/28 主零件重新打开无错误、装配 44/44 引用已持久化。
- 在本机 SOLIDWORKS Premium 2024 SP0.1 中重新打开总装，43 个组件均解析；随后执行“全部保存”。O4 Pro 右侧板主零件也已单独打开、目视核对圆孔与圆弧槽并保存。

## 交付包

- `H440_B1_supplier_DXF_STEP.zip`：7 个碳板 DXF、7 个同名 STEP、加工说明及 SHA-256 清单。
- `H440_B1_printed_parts_STEP.zip`：19 个打印件 STEP、打印说明及 SHA-256 清单。
- 两个压缩包均通过 CRC、内部 SHA-256、文件数量和与磁盘主模型逐字节一致性检查。

## 首件注意事项

- O4 Pro 相机侧螺纹最大旋入深度为 2 mm；应结合侧板、垫片与螺钉头尺寸选取 M2 螺钉长度。
- 碳板 DXF 是最终零件轮廓，不含刀具半径补偿。下单前与供应商确认板厚、公差、最小内圆角、切缝和夹持桥位。
- 目标 6S 1600 mAh 电池目前仍按 78 × 48 × 52 mm 包络验证；批量加工前应实测手头电池。
- 首件应优先验证 O4 Pro 侧板夹紧力、全角度光轴无遮挡、桨叶间隙、碳管胶接和机翼分段连接强度。

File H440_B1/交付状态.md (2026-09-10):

# B1 交付状态

H440 B1 当前数字制造交付已经完成重生成与核验。参数和几何源文件仍为工作目录中的 `build_h440_b1.py`；SolidWorks 文件是由当前 STEP 主模型生成的下游原生交付文件，不是手工重建的参数化特征树。

## 已完成

- B1 全量 STEP/STL/DXF 重新生成；当前零件实体干涉为 0。
- 所有零件 STEP round-trip 有效；7 份碳板 DXF 均已写入 mm 单位。
- 假定 78×48×52 mm 电池在三个代表性纵向位置的机架体积干涉均为 0。
- DJI O4 Pro 相机左右可调侧板已进入主模型；0–90° 以 0.25° 步进共 361 个姿态完成包络和光轴检查，碰撞数为 0，最小电子板净空约 2.128 mm。
- SOLIDWORKS Premium 2024 SP5.0（revision 32.5.0）中，28 个当前组件 STEP 均已保存为 `SLDPRT`，随后关闭并静默重开，未报告打开错误或警告。
- `H440_B1_FRAME.SLDASM` 已由当前 FRAME STEP 重新生成。SolidWorks 导入结构为 1 个根包装子装配 + 43 个生成实例；全部 44 个引用均持久化到仓库内文件，关闭全部文档后重新打开总装，errors=0、warnings=0，且不存在 `Temp/IC~~` 临时引用。详细记录见 `solidworks_native_report.json`。
- 碳板供应商 DXF/STEP 交付包见 `H440_B1_supplier_DXF_STEP.zip`，下料口径见 `供应商交付说明.md`。
- 全部打印件 STEP 交付包见 `H440_B1_printed_parts_STEP.zip`，包含 15 个连接件/设备安装件和 4 个 PLA 机翼分段；说明见 `打印件STEP交付说明.md`。
- 两个压缩包均含中英文说明和 `SHA256SUMS.txt`，并已通过 CRC、清单哈希、文件数量以及压缩包与磁盘主模型逐字节一致性检查。
- PR #1 合并版本已在本机 SOLIDWORKS Premium 2024 SP0.1 中重新打开总装并执行“全部保存”；O4 Pro 右侧板主零件也已单独打开、检查并保存。

## 当前重量口径

CAD 结构净重约 **404.23 g**；紧固件、绑带、防滑垫和胶估算约 **125.92 g**；机架合计预算约 **530.15 g**。这些数值仍属于 CAD/预算结果，首件完成后应以实测称重更新。

## 尚需实物验证

大黄狗 6S 1600 mAh 电池与具体电机、飞塔等实物尺寸仍需装机复核。结构承载、胶接与嵌件强度、振动、动力系统、飞控混控/转换和飞行性能均尚未完成实物验证；数字几何核验通过不能替代这些测试。

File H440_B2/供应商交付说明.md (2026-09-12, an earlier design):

# H440 B2 碳板供应商交付说明

本交付包用于 H440 B2 碳纤维平板零件切割。二维加工以 `DXF/` 中的 7 份 DXF 为准，`STEP/` 中提供同名三维实体用于轮廓、孔位和板厚复核。

## 下料清单

| 件号 | 材料 | 标称厚度 | 数量 |
| --- | --- | ---: | ---: |
| C01_center_side_R_2mm | CFRP 实碳板 | 2 mm | 1 |
| C02_center_side_L_2mm | CFRP 实碳板 | 2 mm | 1 |
| C03_battery_floor_2mm | CFRP 实碳板 | 2 mm | 1 |
| C04_electronics_floor_2mm | CFRP 实碳板 | 2 mm | 1 |
| C05_pylon_R_4mm | CFRP 实碳板 | 4 mm | 1 |
| C06_pylon_L_4mm | CFRP 实碳板 | 4 mm | 1 |
| C07_motor_plate_4mm | CFRP 实碳板 | 4 mm | 4 |

## 加工口径

- DXF 单位为 **mm**；文件为零件最终轮廓，未加入刀具半径、激光/水刀刀缝或夹持补偿。
- 供应商应按实际工艺自行处理刀缝、最小内圆角、引入线、夹持和排版余量，并在加工前确认实际板厚。
- C05/C06 为 4 mm 左右侧承力桁架，无沉头孔；C07 单个文件加工 4 件。
- 碳板优先使用含 0/90° 与 ±45° 铺层的实碳板；若材料体系、铺层或厚度偏差明显，应在下料前反馈。
- STEP 仅用于三维核对；若 STEP 投影与 DXF 出现差异，请暂停加工并反馈，不要自行选择其中一套尺寸。

完整装配、打印件、重量预算和尚待实物验证事项见仓库根目录 `README.md`、`H440_B2/设计与装配说明.md` 与 `H440_B2/BOM与重量预算.md`。

B2中央托板采用榫槽胶接，槽宽2.2mm、槽长12.2mm，角部R0.6避空；先按实际板厚制作试拼件。机臂厚度4mm，禁止与B1的3mm机臂混装。详见《结构复核与装配要求.md》。

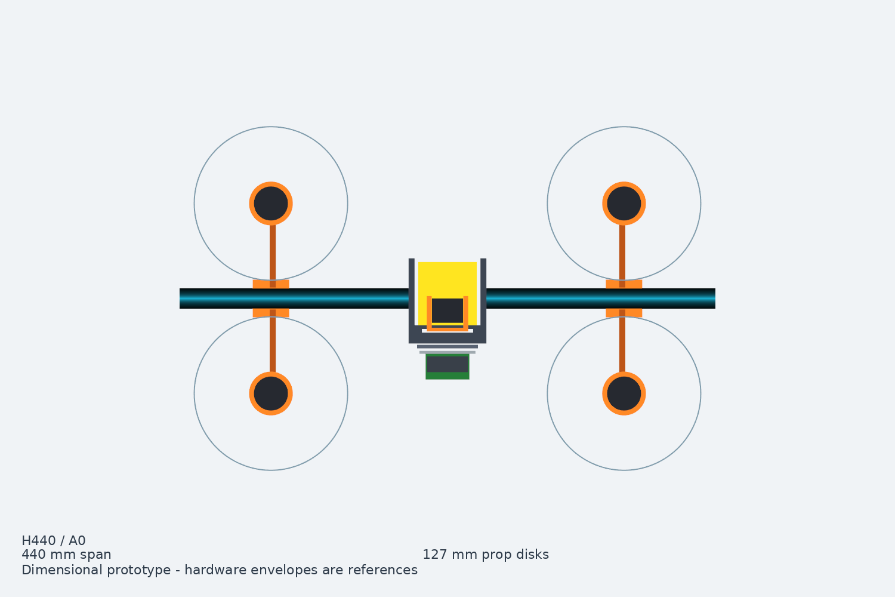
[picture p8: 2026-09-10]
H440_A0/H440_front.png

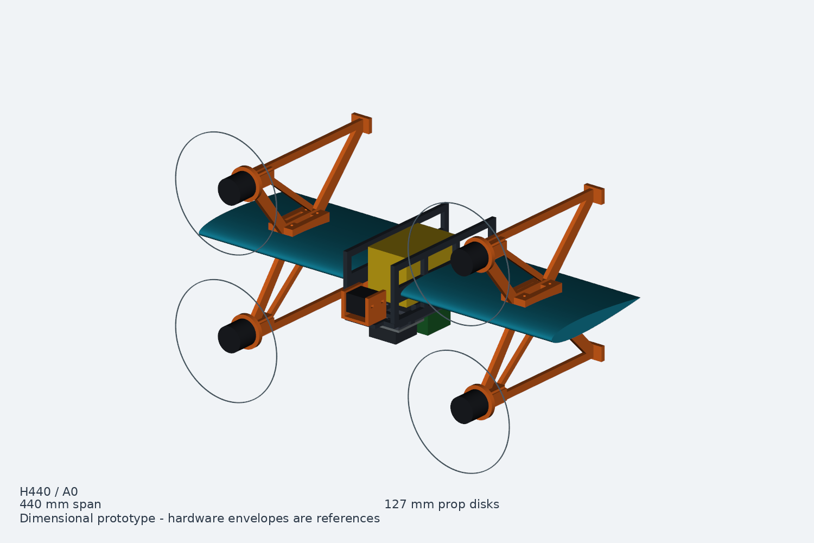
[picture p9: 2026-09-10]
H440_A0/H440_isometric.png

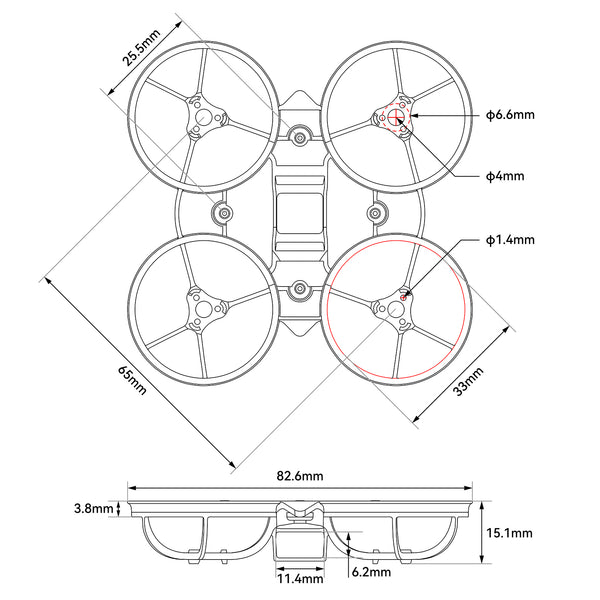
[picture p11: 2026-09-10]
reference/frame_dimensions.jpg

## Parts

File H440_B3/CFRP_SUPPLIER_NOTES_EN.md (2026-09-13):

# H440 B3 CFRP machining notes

All DXFs are 1:1 in millimetres. Use the matching STEP for thickness and feature checks. Cut C01–C04 from 2 mm laminate, one each; C05/C06 from 4 mm laminate, one each; C07 from 4 mm laminate, quantity four. Specify solid CFRP with 0/90 and ±45 reinforcement and obtain the supplier's material certificate.

The B3 center side plates include four through-bolt holes. Keep the widened electronics-deck tongue shoulders, the extended battery-deck camera tabs and the front-center camera clearance cutout. Manufacture the four B3 center plates as a matching set.

Nominal tongues are 2×12 mm; mortises are 2.2×12.2 mm with R0.6 corner relief for cutters no larger than 1.2 mm. Fit to actual laminate thickness and cutter capability using a trial coupon. Do not scale all holes or slots. Through-holes only; no countersinking. Deburr without rounding away structural shoulders. Check closed profiles, tooling access and fit before production.

Purchase/cut four aluminium OD6/ID3.3×62 mm spacers separately. Match their lengths and square their end faces; coordinate the final length with the actual deck-shoulder width. They are not CFRP profiles in this package.

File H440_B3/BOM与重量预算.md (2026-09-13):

# H440 B3 机架 BOM 与重量预算

标准配置：PLA机翼、ABS连接件、TPU95A双端相机侧板、2/4mm碳板、两根碳管、四根铝隔柱。CAD结构净重 **507.3 g**；紧固件、绑带、防滑垫与胶估计 **151.9 g**；机架合计 **659.2 g**。建议按 **680 g** 留重量预算，首件称重前估计范围约 **600–720 g**。

这是机架重量，包含安装五金但不包含电机、桨、飞塔、图传相机、接收机、电池和完整云台。质量按CAD体积×密度估算，金属/软材料为预算假设，尚未切片或称重。

## 标准装机零件

|件号|零件/规格|材料|数量|单重 g|合计 g|
|---|---|---|---:|---:|---:|
|C01_center_side_R_2mm|中央右侧板，2mm碳板，四点横向螺栓锁紧|CFRP|1|11.37|11.37|
|C02_center_side_L_2mm|中央左侧板，2mm碳板|CFRP|1|11.37|11.37|
|C03_battery_floor_2mm|电池托板，2mm，双纵向穿带槽|CFRP|1|22.54|22.54|
|C04_electronics_floor_2mm|开放飞塔/图传托板，2mm|CFRP|1|20.24|20.24|
|T03_center_spacer_6x3p3_L62|铝合金精密隔柱OD6/ID3.3×62，配M3贯穿螺栓|AL6061|4|3.30|13.20|
|T01_main_10x8_L420|碳管OD10/ID8×420，整根贯穿|CFRP|1|19.00|19.00|
|T02_rear_6x4_L420|碳管OD6/ID4×420，整根贯穿|CFRP|1|10.56|10.56|
|P02_main_collar|胶接翼梁法兰套，内孔Ø10.3，2-M3嵌件|ABS|4|4.43|17.73|
|P03_rear_collar|胶接翼梁法兰套，内孔Ø6.3，2-M3嵌件|ABS|4|5.08|20.34|
|C05_pylon_R_4mm|右侧4mm交叉加强桁架，四孔电机座接口|CFRP|1|66.27|66.27|
|C06_pylon_L_4mm|左侧4mm交叉加强桁架，四孔电机座接口|CFRP|1|66.27|66.27|
|C07_motor_plate_4mm|电机板4mm；16孔距电机/24孔距转接|CFRP|4|7.37|29.49|
|P04_motor_clevis|4mm桁架四孔U座，外侧三角筋加强，4.15mm夹槽|ABS|4|12.77|51.07|
|P05_tail_shoe|可更换着陆脚套，胶接4mm侧板边缘|ABS|4|1.77|7.10|
|W01_inner_R|右翼内段，0.6mm标称皮+管套/0.8mm肋|PLA|1|35.09|35.09|
|W02_outer_R|右翼外段，0.6mm标称皮+管套/0.8mm肋|PLA|1|24.68|24.68|
|W03_inner_L|左翼内段，0.6mm标称皮+管套/0.8mm肋|PLA|1|35.09|35.09|
|W04_outer_L|左翼外段，0.6mm标称皮+管套/0.8mm肋|PLA|1|24.68|24.68|
|P06R_O4Pro_camera_side|TPU95A右侧板，上下各双M3固定，OD5限压套，M2弧槽调角|TPU|1|8.77|8.77|
|P06L_O4Pro_camera_side|TPU95A左侧板，上下各双M3固定，OD5限压套，M2弧槽调角|TPU|1|8.77|8.77|
|P07_O4Pro_adapter|O4 Pro25.5-M2适配板|ABS|1|3.65|3.65|

## 五金与装配消耗品

以下为完整4孔电机板连接方案；不为减轻几克重量擅自删减连接螺钉。螺钉长度按实物复核，尤其电机螺钉不得顶到绕组。

|件号|规格/用途|数量|单重估计 g|合计 g|
|---|---|---:|---:|---:|
|H01|M3×8钢螺钉：碳板到法兰套|16|0.65|10.40|
|H02|M3×12钢螺钉：电机板16＋图传转接4|20|0.90|18.00|
|H03|M3×22钢螺钉：电机U座四孔夹侧板，按垫片实测选长|16|1.30|20.80|
|H04|M3×12钢螺钉：TPU相机侧板上下各四点|8|0.90|7.20|
|H05|M3×6电机螺钉，长度需按电机复核|16|0.50|8.00|
|H06|M3防松螺母|46|0.38|17.48|
|H07|M3薄平垫片|100|0.08|8.00|
|H08|M3热熔嵌件，外径按Ø4.2试孔匹配|16|0.30|4.80|
|H09|4根飞塔绝缘柱＋配套尼龙螺钉|1|6.00|6.00|
|H10|图传M2紧固/胶圈套件|1|2.00|2.00|
|H11|图传间隔柱、绝缘薄垫套件|1|3.00|3.00|
|H12|20mm宽电池绑带|2|5.00|10.00|
|H13|36×78×4mm防滑泡棉垫|1|2.00|2.00|
|H14|O4 Pro相机M2侧螺钉/薄垫片＋导线固定件；实际螺纹拧入不得超过2mm|1|3.00|3.00|
|H15|管套/翼套/脚套及中央榫槽胶接胶，装机留存量|1|10.00|10.00|
|H16|电机夹槽0.05/0.10mm硬质金属配合垫片组，按实测选择|4|0.40|1.60|
|H17|M3×75横向贯穿螺栓，实际螺纹与尾端伸出需核对|4|4.30|17.20|
|H18|TPU固定脚铝合金限压套OD5/ID3.2×3.0mm|8|0.10|0.80|
|H19|TPU固定脚M3大垫片OD8，覆盖限压套与TPU|8|0.20|1.60|

## 替代件，不能重复计入标准装机重量

|件号|说明|质量 g|
|---|---|---:|
|P08_O4_adapter|O4普通版软安装板|3.63|
|P09_analog_adapter|模拟20-M2安装板|3.65|
|P10_gimbal_dock|单轴云台预留板，非整套云台|7.74|
|P11_O4_camera_insert|14.4mm相机衬块|2.76|
|P12_analog_camera_insert|19.4mm相机衬块|1.92|
|P13_camera20_insert|20.4mm相机衬块|1.76|
|P14_camera_cradle_legacy|26mm通用相机座；O4普通版/模拟相机兼容替代件|8.77|

O4/模拟图传板替换P07；P10云台接口板作为独立替代配置使用，不与P06R/P06L O4 Pro相机侧板重复计入。云台预留只包括接口，舵机、转轴和运动支架须另设计并单独计重。P14通用相机座及P11/P12/P13减径衬块按所选非O4 Pro相机配置追加。

## 材料口径与采购下料

- PLA按1.24、ABS按1.04、TPU按1.21、铝合金按2.70、碳板/碳管按1.60 g/cm³预算；均须用实际耗材和称重核对。
- 2mm碳板：C01/C02/C03/C04各1；可先按400×250mm毛坯排版，切割厂需用DXF核实刀缝、夹持和余料。
- 4mm碳板：C05/C06各1；建议410×210mm毛坯排版。侧板外形约194×173mm，两片并排；无沉头孔，保留厚度。
- 4mm碳板：C07×4；100×100mm毛坯可排4片36×36mm电机板。
- 两种碳管各买500mm标准料，分别截取420mm；主梁10/8、后梁6/4。用整根管，不在机身中心对接。余料可做胶接和嵌件试验。
- 碳板优先采购含0/90及±45铺层的实碳板；碳管优先有环向纤维的卷制管。不能以外观碳纹或单向拉挤细管替代而不重新验证。
- 2、4mm两种平板和直管可用常规二维切割及定尺切断，连接件复用相同打印件；成本主要来自小批量碳板切割，不需要5mm全机板或铝合金CNC大件。未取得本地报价，不给出虚构采购总价。

## 整机重量如何估计

完整起飞重量 = 本表机架重量 + 4电机 + 4桨 + 飞塔 + 图传/相机/天线 + 接收机/线材 + 电池 + 可选完整云台。

仅用于预算的例子：四电机合计140g、四桨20g、飞塔35g、O4 Pro全套45g、接收机/线材25g、电池280g，则整机约 **1204 g**。这些电子/电池质量未经型号确认；不是大黄狗电池的厂家规格。换图传、电池或加云台后必须重新计算。

## 材料参考

- [Polymaker PLA技术数据](https://polymaker.com/wp-content/tech-docs/PolyLite_PLA_PIS_EN_V1.1.pdf)：PLA密度随产品/条件变化。
- [Easy Composites碳板](https://www.easycomposites.co.uk/high-strength-carbon-fibre-sheet)：解释准各向同性铺层及不同标称厚度的实际厚度公差。
- [卷制碳管的纵向与环向铺层说明](https://www.easycomposites.co.uk/8mm-woven-finish-carbon-fibre-tube)：仅用于材料构造参考，不把该8mm商品当成本BOM的10mm主梁。

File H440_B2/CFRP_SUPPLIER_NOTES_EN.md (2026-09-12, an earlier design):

# H440 B2 CFRP Supplier Notes

`H440_B2_supplier_DXF_STEP.zip` contains the cutting definition for the H440 B2 flat CFRP parts. Use the seven files in `DXF/` for 2D machining. Same-name solids in `STEP/` are supplied for contour, hole-location and nominal-thickness reference.

| Part | Material | Thickness | Qty |
| --- | --- | ---: | ---: |
| C01_center_side_R_2mm | Solid CFRP sheet | 2 mm | 1 |
| C02_center_side_L_2mm | Solid CFRP sheet | 2 mm | 1 |
| C03_battery_floor_2mm | Solid CFRP sheet | 2 mm | 1 |
| C04_electronics_floor_2mm | Solid CFRP sheet | 2 mm | 1 |
| C05_pylon_R_4mm | Solid CFRP sheet | 4 mm | 1 |
| C06_pylon_L_4mm | Solid CFRP sheet | 4 mm | 1 |
| C07_motor_plate_4mm | Solid CFRP sheet | 4 mm | 4 |

- DXF units are millimetres. Curves describe final contours and exclude tool-radius, kerf and workholding compensation.
- Apply process-specific kerf, lead-ins, minimum radii, nesting clearance and holding tabs. Confirm actual sheet thickness.
- C05/C06 are structural trusses without countersinks. Cut four copies of C07 from its single DXF.
- Prefer solid laminate containing 0/90° and ±45° plies. Report material, layup or thickness deviations before cutting.
- STEP files are inspection references. If a STEP projection differs from its DXF, stop and request clarification.

Use the archive's `SHA256SUMS.txt` to verify transfer integrity.

B2 uses bonded mortises for the center trays: nominal slots 2.2 x 12.2 mm with R0.6 corner relief. Dry-fit actual laminate before full production. Both pylons are 4 mm and must not be mixed with B1 parts.

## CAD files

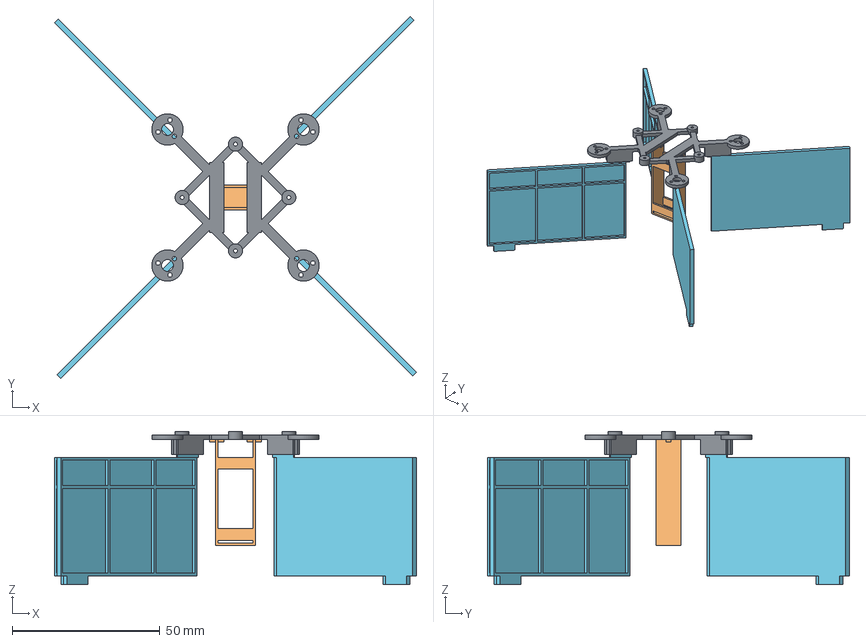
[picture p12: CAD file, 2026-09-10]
X120_A1/X120_assembly.step
122.3 x 122.3 x 51.8 mm
hub
wing_1
wing_2
wing_3
wing_4
battery_cage

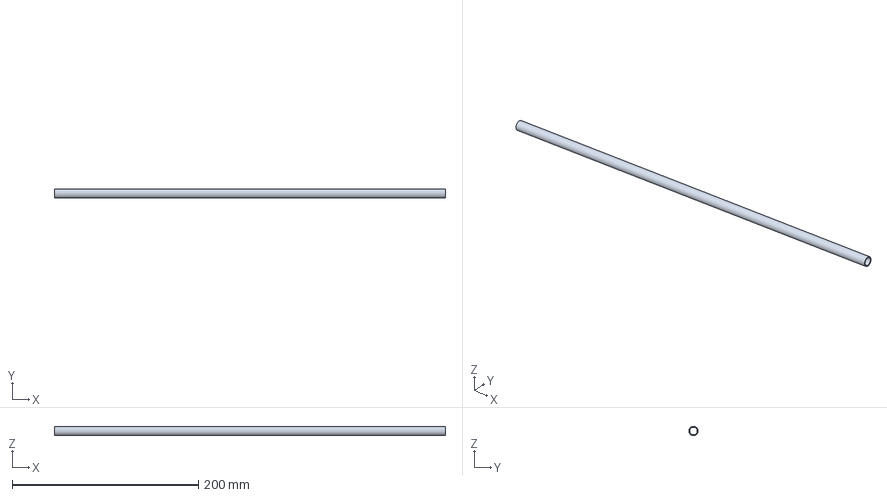
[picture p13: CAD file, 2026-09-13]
H440_B3/T01_main_10x8_L420.step
420.0 x 9.99 x 10.00 mm

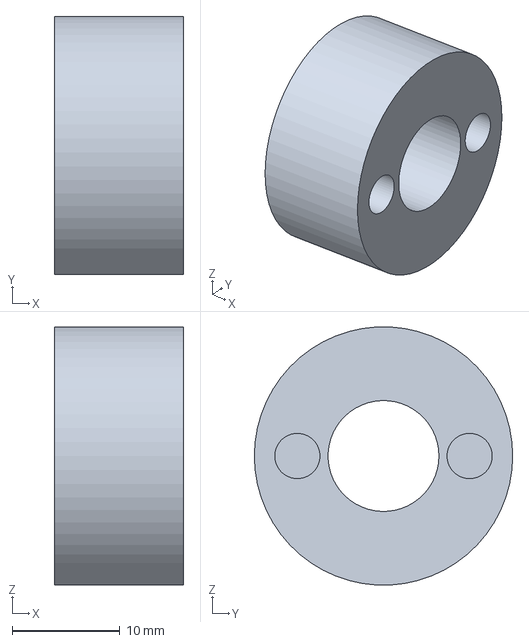
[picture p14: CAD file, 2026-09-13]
H440_B3/P02_main_collar.step
12.0 x 24.0 x 24.0 mm

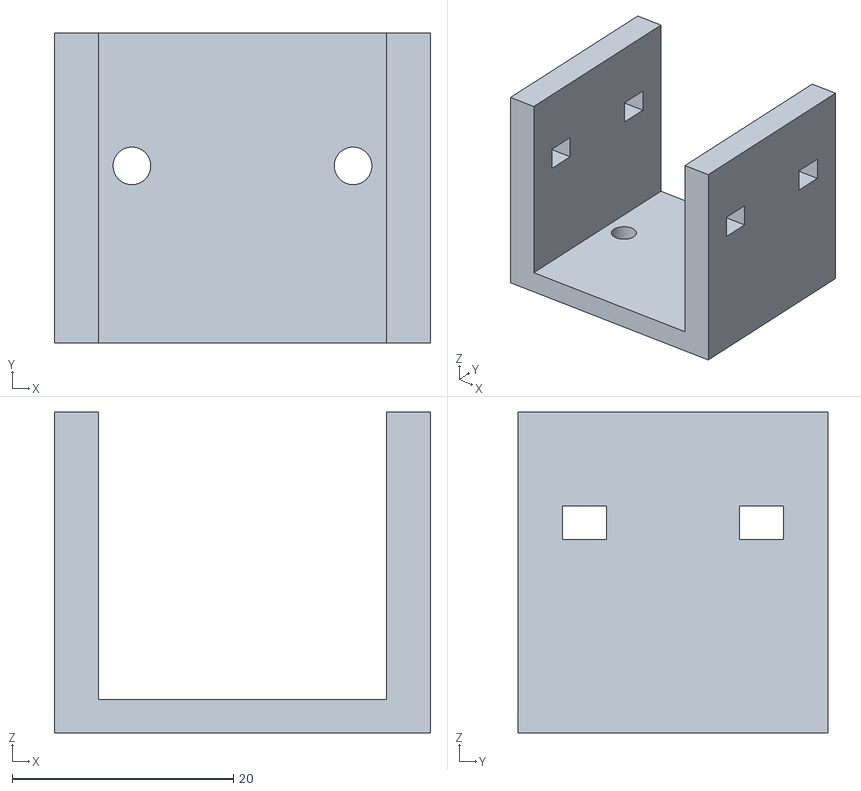
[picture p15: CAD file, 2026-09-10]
H440_A0/10_camera_cradle_26clear_print.stl
34.0 x 28.0 x 29.0

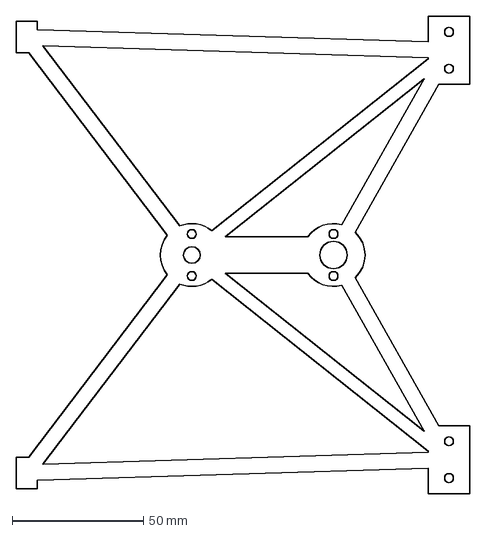
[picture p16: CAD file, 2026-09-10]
H440_B1/C05_pylon_R_3mm_cut_mm.dxf
173.0 x 182.0 mm

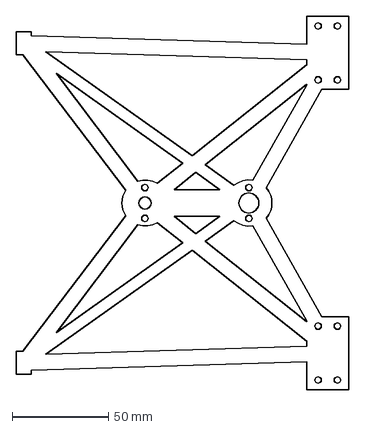
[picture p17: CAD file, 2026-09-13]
H440_B3/C05_pylon_R_4mm_cut_mm.dxf
173.0 x 194.0 mm

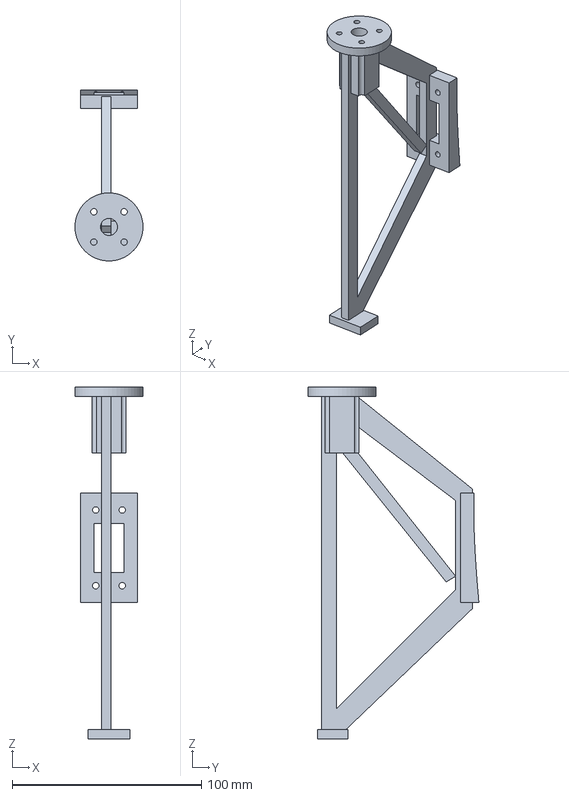
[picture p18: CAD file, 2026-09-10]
H440_A0/05_pylon_lower.step
36.0 x 90.3 x 186.0 mm

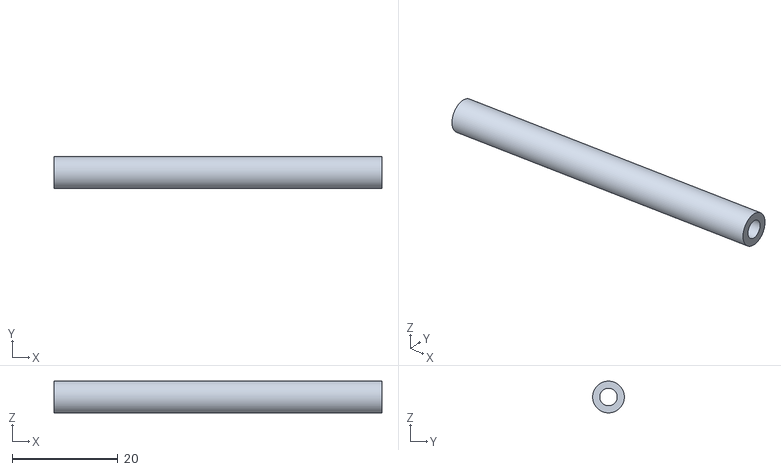
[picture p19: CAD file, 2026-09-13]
H440_B3/_instance_07.stl
62.0 x 6.00 x 6.00

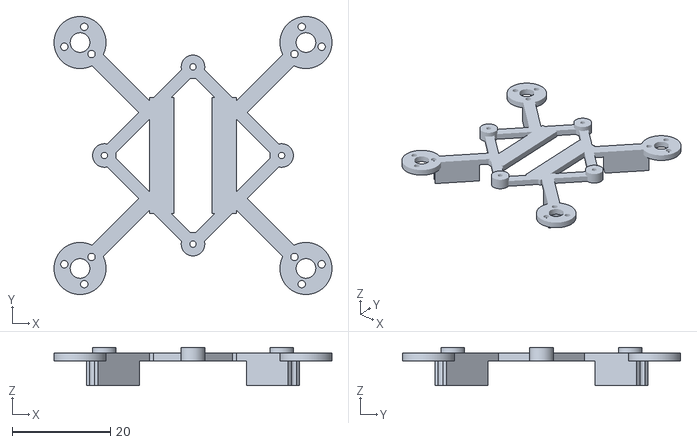
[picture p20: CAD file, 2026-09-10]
X120_A1/hub_print.stl
56.6 x 56.6 x 7.80

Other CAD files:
H440_B3/SolidWorks_Assembly_Parts/T01_main_10x8_L420.SLDPRT
H440_B3/SolidWorks_Assembly_Parts/P02_main_collar_pylon_R.SLDPRT
H440_B3/SolidWorks_Assembly_Parts/P02_main_collar_center_L.SLDPRT
H440_B3/SolidWorks_Assembly_Parts/P02_main_collar_pylon_L.SLDPRT
H440_B3/SolidWorks_Assembly_Parts/P02_main_collar_center_R.SLDPRT
H440_B1/SolidWorks_Assembly_Parts/H440_B1_FRAME_IMPORTED.SLDASM
H440_B3/P02_main_collar_print.stl
H440_B3/SolidWorks_Assembly_Parts/Battery_floor.SLDPRT
H440_B3/SolidWorks_Assembly_Parts/Electronics_floor.SLDPRT
H440_A0/01_center_cradle.step
H440_A0/01_center_cradle_print.stl
H440_A0/02_wing_right.step
H440_A0/02_wing_right_print.stl
H440_A0/03_wing_left.step
H440_A0/03_wing_left_print.stl
H440_A0/04L_pylon_upper_left.step
H440_A0/04L_pylon_upper_left_print.stl
H440_A0/04_pylon_upper.step
H440_A0/04_pylon_upper_print.stl
H440_A0/05L_pylon_lower_left.step
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

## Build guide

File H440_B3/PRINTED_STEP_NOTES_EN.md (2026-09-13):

# H440 B3 printable STEP delivery

The package contains 18 printed-part definitions. Print P06R/P06L camera sides in TPU 95A, W01–W04 wings in PLA, and the remaining P parts in ABS. Follow BOM quantities and optional status. Individual parts fit a 256 mm printer; assembly coordinates are not print orientations.

Camera walls are 5 mm thick and both mounting feet are 3 mm thick. Use eight M3 mounting screws, eight OD5/ID3.2×3 mm metal crush sleeves and broad washers across the two sides. Use dense 95A prints with solid feet/hole regions and at least six perimeter walls. First print fit coupons for the 5.1 mm sleeve holes and M2 slots. Match sleeve length to actual foot thickness to avoid either crushing TPU or leaving it loose.

Orient and support the projecting feet without damaging the camera contact faces or curved slots. Keep load-carrying motor clevises and spar collars in ABS. Do not substitute TPU for these structural fittings. Check M2 screw engagement, the full angle sweep, warm angle retention and vibration after assembly. Dual-ended mounting does not make TPU rigid.

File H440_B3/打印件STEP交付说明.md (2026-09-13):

# H440 B3 打印件 STEP 交付

本包包含 18 种打印件 STEP。P06R/P06L 相机侧板使用 TPU 95A；W01–W04 机翼使用 PLA；其余 P 件使用 ABS。按 BOM 数量打印，带 optional 的适配件不属于同一套标准装机数量。所有零件分件尺寸适配 256 mm 打印板，装配 STEP 坐标不能直接当作最佳打印朝向。

TPU 侧板名义壁厚 5 mm，上下固定脚各厚 3 mm。两块侧板合计八处 M3 固定，配八个 OD5/ID3.2×3 mm 金属限压套及大垫片。推荐 95A 致密打印，脚和孔周围实心，至少六道外壁；用实际耗材先做 Ø5.1 套孔和 M2 槽宽试片。限压套长度按实测脚厚配合，不能凸起过多使脚松动，不能过短使 TPU 被压瘪。

侧板平放打印时固定脚可能形成悬挑；选择开口面和支撑方向，支撑不得损伤 M2 弧槽和相机接触面。机翼沿既有分件方式打印，PLA 不能暴晒或靠近高温电调。电机 U 座与承载管套仍用 ABS，不能随相机侧板一起换成 TPU。

安装后检查 M2 垫片、螺纹拧入长度和 0–90° 调角；完成热态角度保持和振动测试。双端固定不等于 TPU 不变形。

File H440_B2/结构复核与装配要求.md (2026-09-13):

# B2 结构复核与装配要求

## 改动落实

1. 取消电池仓的高侧围板，仅保留碳管与上下托板连接所需的低位中央腹板；腹板最高 Y=22 mm，电池由两条 20 mm 绑带及防滑泡棉固定。
2. 取消 P01 角码和全部 8 个角码装配实例。C03/C04 各有左右两组一体榫舌，共 8 处榫槽连接；名义榫舌 2×12 mm，槽 2.2×12.2 mm，槽角 R0.6 避空。榫舌进入侧板 1.8 mm，闭口槽定位承剪、胶接防退出。
3. C05/C06 从 3 mm 改为 4 mm，主要杆宽从 6 mm 增至 8 mm、原 5 mm 斜杆增至 8 mm，新增 6 mm 交叉杆，节点连接为一体切割。
4. 四个电机 U座均加长夹持区、增设三角筋，两个夹紧孔改为四孔。孔中心间距为 28×10 mm；对应机臂孔同步修改，夹槽名义 4.15 mm。
5. 两侧机臂仍以 X=±145 mm 为中心。梁套站位随板厚调整 0.5 mm；翼分段间隔从 3.4 mm 改为 4.4 mm，脚套夹槽改为 4.3 mm。
6. 飞塔孔距、O4 Pro 相机的 M2 弧槽机构、电池穿带槽及前后配平空间保留。

## 比较计算的范围

`../structure_screening.py` 使用 3D Euler–Bernoulli 梁单元，每节点 6 自由度。新旧机臂均在两处碳管中心节点固定，交叉杆交点合并为刚节点。材料假定 E=32 GPa、G=12 GPa。程序先以两个弯曲方向的悬臂梁闭式解自检，并检查求解后的自由节点平衡残差。

E 仅参考常见准各向同性碳板的量级；并非本机采购材料证书。G 是筛选假定。不得用碳纤维丝的纵向模量当作整块碳板模量。[碳板厂家材料及铺层说明](https://www.easycomposites.co.uk/high-strength-carbon-fibre-sheet)

输入工况都是设计比较假设，不是四颗指定电机已测数据：每电机轴向载荷 15 N、正负差动 15 N、侧向载荷 3 N、反扭矩 0.15 N·m。每块机臂有上下两电机，左右为镜像。

|比较工况|B1 电机节点位移 mm|B2 电机节点位移 mm|B1 转角 °|B2 转角 °|
|---|---:|---:|---:|---:|
|每电机轴向 15 N|0.0323|0.0104|0.0231|0.0078|
|轴向正负差动 15 N|0.0323|0.0104|0.0231|0.0078|
|每电机侧向 3 N|1.0330|0.2809|0.8549|0.2403|
|反扭矩 0.15 N·m|0.6231|0.1730|0.8969|0.2509|

单根 8×4 mm 杆相对原 6×3 mm 杆，面外截面惯性矩提高约 3.16 倍。螺栓组孔位的极距平方和由 98 增至 884 mm²；这只说明抵抗连接转动的孔位力臂增大，不能直接宣称接头刚度提高同样倍数。

梁模型的最大名义弯曲/轴向极纤维应力在侧向工况由约 21.14 MPa 降至 7.48 MPa，但忽略开孔应力集中、层间剥离、铺层各向异性、局部屈曲、胶接、螺栓滑移和 ABS 柔度。因此**未给出结构强度合格或飞行无震荡结论**。该计算也没有获得整机固有频率或控制环稳定裕度。

## 接头和电机座装配

- 先干拼两根碳管、梁套、中央低腹板及两块托板，再确定榫槽胶接。闭口槽要在两侧板最终固定前插入，禁止装好中心框后硬掰托板。
- 2.2 mm 槽宽按实测板厚和工艺公差调整；榫槽接头用胶固定，不能只靠松配合承担防退出作用。用同批 2 mm 碳板制作至少三个榫槽拉拔/剪切试样，胶型和表面处理依照实际胶粘剂要求。
- 电机 U座夹槽总间隙名义为 0.15 mm。用 0.05/0.10 mm 硬质薄垫片按实测配合选装，消除可感知游隙，再对称拧紧四颗贯穿 M3。不得靠把 ABS 压弯来合缝。
- 四孔机臂与四孔 U座成套使用，禁止与 B1 两孔零件混装。使用防松螺母和薄平垫；M3×22 长度按实际厚度确认，螺纹完全越过防松圈，但不与机翼或其他结构接触。
- ABS 筋与夹持壁需足够实心壁厚；打印朝向与填充由切片和拉拔/弯曲样件确定。不要将螺钉夹紧力施加到空心填充薄皮，也不要用软橡胶安装整个电机座。
- 4 mm 电机板保留四点固定。具体电机孔距仍需确认，电机螺钉不得顶到绕组。电机座附近的孔、筋和工具入口须用实物扳手试装。
- 两根贯穿碳管、胶接梁套和 ABS 热蠕变仍是整机柔度来源。每次温升循环和首轮试车后检查连接游隙、拧紧标记与胶缝。

## 实物验收建议

以下为建议首件筛选门槛，不是已经测得的结果。基准加载装置应固定两根碳管的中央安装区，使用假电机块，禁止挂载在带桨电机上。

1. 逐一对四个电机位加载正反轴向 15 N、侧向 3 N，测位移并卸载复测；左右和上下位移差异明显时排查接头。若实际台架最大推力超过 15 N，按实测最大推力重新制定载荷。
2. 先用小载荷确认线性，再经审核确定极限/证明载荷；本版未声明 15 N 是可保证承受的工作载荷。
3. 检查榫槽、碳管胶缝、螺母和 ABS 座无裂纹、无滑移、无持续增长的变形；任何手感游隙都须在试飞前消除。
4. 机架做敲击响应和无桨电机逐级转速扫描，记录飞控陀螺仪频谱；装桨试验应在隔离台架进行。出现窄带峰值随转速放大、座体晃动或温升后刚度下降时停止升级测试。
5. 完成整机静载和温升蠕变测试后，再调滤波、PID 和混控。滤波参数不能替代修复机械松动；本设计尚不能保证转换飞行稳定性。

## 当前交付限制

几何与 STEP/DXF 检查可复现；B2 的 27 种 SLDPRT 与 35 实例 SLDASM 已在 SolidWorks 2024 SP0.1 完成保存和重开检查。总装复开错误为 0、组件缺失为 0；重建并保存后已消除内部 ID 不匹配警告，仍保留 `NeedsRegen` 警告码 32，因此制造前须在接收方 SolidWorks 环境中强制重建并另存一次。B1 原生档案仅作历史版本，不与 B2 混用。

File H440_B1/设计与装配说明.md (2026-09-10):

# H440 B1 混合材料版本

以本目录为准，A0保留作历史草案。本版主翼采用PLA，其余连接件用ABS，主要承力件改用2/3/4mm碳板及连续碳管。它是完成几何检查的工程样机，尚未做实物载荷、振动、胶接或飞行验证。

## 已落实到模型的改动

- 440mm翼展、140mm弦长；主翼四段打印，内段109.3mm、外段73.3mm。碳板站位两侧留0.2mm，形成3.4mm分段间隔。最大打印件外廓小于256mm，STL已放到打印平台Z=0。
- 主梁为10/8×420mm碳管，后梁为6/4×420mm碳管，均整根横穿机身和两侧机翼。翼管位于Y=0、Z=-44/-98；中央框与电机支撑直接连接管上的胶接法兰套，不依赖PLA翼皮承担电机载荷。
- 2mm碳板用于中央两侧框、电池板和电子板；3mm用于左右各一块上下联体桁架；4mm用于四块电机板。电机座不直接压在ABS上，电机先安装到碳板，再由U形连接件与侧桁架连接。
- 保留30.5mm飞塔孔距，O4/O4 Pro/模拟图传可换板。O4 Pro相机使用独立左右ABS侧板，按20mm机身宽度留20.4mm净宽，每侧以一颗M2作枢轴、另一颗M2沿R16弧槽锁紧，可在朝前至朝下0–90°范围内连续调角。O4普通版/模拟相机继续使用26mm通用相机座和14.4/19.4/20.4mm衬块作为替代配置；单轴云台保留20mm双孔接口。模拟板仅覆盖20×20mm M2规格，其他模拟图传应另配板。
- 电池板改为双条132×3mm纵向穿带槽，绑带位置可沿槽调整。不存在固定两绑带站位限制短电池移动的问题。

## 电池与配平

电池仍以假定的78×48×52mm包络建模，未收到大黄狗6S1600mAh的实测数据。托板宽62mm、长148mm，电池两侧有穿带空间。中央侧框内侧间距62mm，顶部开放。

电池下方装36×78×4mm防滑泡棉，泡棉置于中央，避开两侧角码。电池底面Y=21、顶面Y=73；角码顶面Y=20，因此电池移动时不会顶到角码。已对电池中心Z=-105、-75、-45三个位置检查与机架的体积干涉，结果为零。建议使用±30mm有效行程，端部各留约5mm；148-78=70mm只是总几何行程。

两条20mm绑带可先以40mm间距布置，再随电池一同移动。穿带后确认不绕进碳管、电子线束或相机线。碳板槽边去毛刺并做软边保护，泡棉和绑带是装配必需件，已计入重量预算。

电池上移会改变Y向重心：这不是只调纵向就能忽略的变化。使用实际部件称重求三轴重心；主翼25%弦处Z=-40仅为测量参考，并非已验证的配平目标。模型没有宣称±30mm电池行程必然覆盖所有电装组合的目标重心。

## 装配与连接

1. 按DXF切割碳板；单位mm，文件为零件最终轮廓，未加刀具半径补偿。切割厂应核对实测板厚、孔径、最小圆角和夹持余量。不要把STEP投影误当成另一套加工尺寸。
2. 两根碳管截取420mm、倒钝端口。先试装法兰套和四段翼壳，再按装配坐标定位；胶未固化前以平整平台核对两管平行及左右对称。
3. 主梁套孔Ø10.3、后梁套孔Ø6.3，名义单边胶层间隙0.15mm。胶接套长度12mm，碳管不得打穿孔或用径向紧定螺钉夹伤。按胶粘剂要求准备碳管/ABS表面，并先做同批次胶接拉拔和扭转试样；ABS胶接性能不能仅靠材料名称推定。
4. 八个法兰套各使用2个M3嵌件，嵌件导孔Ø4.2、深6mm。嵌件型号和打印收缩需通过小样确认。中央碳板和两侧桁架以M3螺钉连接套端面；右侧中央套X=19..31，右侧桁架套X=131.5..143.5，左侧镜像。
5. 四段PLA翼壳的管套与碳管胶接，管套和肋保持翼型及传递升力。外翼端管孔开放，用薄胶带封口即可；禁止在管端塞入重实心填料。胶接式翼壳不是免工具快拆机翼。
6. ABS角码各用两颗正交M3螺钉连接托板与侧框，电池4个、电子4个。垫片分散载荷，防松螺母避免直接在薄碳板上攻丝。
7. 电机U座夹住3mm桁架，夹槽净宽3.2mm。两颗M3贯穿U座侧向固定，四颗M3连接上方4mm碳电机板。16×16mm电机孔暂定；电机具体型号尚未确认，若不同只需重做C07电机板。
8. 飞塔和图传安装于下方开放电子板，使用绝缘柱、胶圈和垫片。碳板导电，板背焊点和电源接头不能接触碳材。天空端的散热表面保持通风，ABS/PLA都不能代替散热片。
9. O4 Pro相机左右侧板各以两颗M3固定到C04电子板；相机每侧用一颗M2枢轴螺钉和一颗M2弧槽锁紧螺钉。调角后对称拧紧两侧，实际螺纹拧入相机壳体不得超过DJI标注的2mm。CAD按相机20×23.3×25.55mm包络对0–90°做0.25°步进扫描，最小电子板净空约2.13mm；首件仍需用真机检查壳体圆角、镜头、排线和垫片余量。
10. 四个脚套胶接到桁架尾端，作为可更换磨损件。胶接固化及连接件检查后再装动力部件。

## 打印与材料选择

机翼标称皮厚0.6mm、肋0.8mm、管套径向壁厚0.6mm，部分前/后缘区域为实心封闭截面。建议0.4mm喷嘴、0.16–0.20mm层高，用切片器可变线宽或校准后的0.6mm单道线实现薄皮；必须检查逐层预览，不能设置两道0.4mm墙后仍假设质量和外形不变。可先打一段翼皮/管套试样，若设备不能稳定完成0.6mm壁，改为0.8mm并重新估重。

翼件以展向竖直打印；连接件按`_print.stl`方向开始检查，U座、相机座的局部悬空面可加支撑。CAD包络检查不是切片验证，尚未证明指定打印机可以无缺陷打印薄皮、桥接或嵌件孔。

选用ABS连接件是为了降低热软化风险和密度，并非宣称其层间强度必然优于PLA。电机、天空端附近不要改为普通PLA而不做温升试验。PLA可作为低成本配装试样，正式材料仍应通过力学试条和部件试验选择。

碳板采用实碳多方向铺层，碳管采用含环向纤维的卷制管；此处未用供应商力学保证值。加工时按加工服务商的复合材料粉尘、刀具和边缘处理规范执行。

## 强度、重量和成本取舍

直接承力路径为：电机→4mm碳电机板→U座→3mm桁架→胶接法兰套→两根贯穿碳管→中央碳板。PLA翼皮不再承担电机根部连接载荷。双梁间距54mm提供抗扭力臂，主梁选10/8而非更小直径，增加的材料质量只有数克，却提高了截面惯性矩。

简化梁算例仅作尺寸筛选：10/8管截面惯性矩约289.8mm⁴，6/4管约51.1mm⁴；假设两管等E=70GPa、共同承受40N单侧横向载荷、中心板到侧桁架113mm等效悬臂，则端部挠度约0.81mm，主梁外纤维应力约66MPa。此算例忽略胶接、开孔、层合各向异性、连接滑移和三维扭转，**不构成强度验收**。

几何结构约406.6g，比A0最后一版全打印几何约561.6g轻27.6%。碳板加工和五金增加成本，换取承力路径和可更换电机板；装机五金、绑带和胶计入后机架预计531g，按550g预算。不能把406.6g当成可直接起飞的整机质量。

当前电装预算例子约1.08kg起飞重量，450mm级机翼对应较高翼载。必须实测四电机最低工作电压下推力、电流与温升，再做无桨方向检查、部件载荷测试和约束悬停。无舵面前飞依赖电机持续控制，飞控板具体固件目标和混控还未确认；不能直接使用普通穿越机自稳参数推断能自动转换。

## 文件与验证

- `H440_B1_FRAME.step`：有零件层级和材料颜色的机架装配。
- `H440_B1_LAYOUT.step`：含假定电池、动力、图传等参考包络，参考包络不能加工/打印。
- `H440_B1_FRAME_multibody.step`：同一机架的多实体导入版本，供SolidWorks稳定打开并保存。
- `P06R_O4Pro_camera_side.step` / `P06L_O4Pro_camera_side.step`：O4 Pro左右可调相机侧板；旧26mm通用相机座保留为其他相机替代配置。
- 各件STEP、打印STL、7份碳板DXF，以及`BOM与重量预算.md`。
- `geometry_report.json`记录质量口径、全部零件有效性、STEP重新读取检查、零件干涉、DXF单位、电池三位置检查及O4 Pro相机0–90°扫掠检查。

SolidWorks文件使用导入实体，并非重新逐项建立完整草图特征树；可编辑参数源为上级目录`build_h440_b1.py`。若换电池、电机孔距或图传型号，应修改源模型并重新生成、复核。

尚未完成：实际电池/电机/飞塔尺寸确认、切片称重、胶接和嵌件拉拔、整机有限元/振动/载荷试验、动力及飞行验证。

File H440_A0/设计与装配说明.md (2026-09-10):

# H440 A0 H形无舵面尾座机架

本版为尺寸配装与结构样机。已生成精确B-rep实体和分件STL，完成几何有效性、打印包络和已安装打印件干涉检查。尚未完成切片实测、有限元、材料试条、动力台架或飞行验证，不能作为强度或可飞保证。

## 布局与尺寸

坐标：X为翼展，Y为前飞时上下，Z为前飞方向。前视H形：中央水平主翼、左右上下四个桁架支撑，四电机平行向前。主翼没有活动舵面；单轴舵机板仅用于相机云台。

|项目|尺寸/定义|
|---|---|
|主翼翼展|440 mm|
|主翼弦长|140 mm，前缘Z=-5，后缘Z=-145|
|翼型|NACA0012离散闭合对称截面，最大厚16.8 mm；未做低雷诺数优化|
|主翼外露面积|0.05264 m²，左右各188×140 mm；0.0616 m²为含中央遮挡的矩形参考面积|
|电机中心|X=±145，Y=±78 mm|
|电机|用户指定2306.5 1850KV；外形参考件为Ø28×25 mm，需核对具体型号|
|电机安装|暂按16×16 mm、4-M3；Ø9中心避空，座板5 mm|
|桨盘|直径127 mm，参考平面Z=46 mm，未模拟真实桨叶形状和挠曲|
|桨尖最小间隙|上下29 mm，左右163 mm；水平总桨盘包络417 mm|
|机架前后长|196 mm；含参考桨盘216 mm，不含可能突出的插头/天线|
|脚底|Z=-169 mm，四个加厚着陆脚，位于左右支撑尾部|
|飞塔|30.5×30.5 mm、通孔Ø3.4；参考板36×36、堆叠高度23 mm|

## 电池仓与重心

电池实测数据尚未提供；当前黄色包络是假定的78长×48宽×52高 mm，**不是已确认的大黄狗规格**。仓内宽54 mm，纵向有效长度148 mm，顶部开放。电池底面靠双绑带桥上表面Y=-22，顶部到侧框上沿55 mm。允许高于框沿，但必须确认绑带长度及左右重心。

两处绑带桥位于Z=-108和-48，穿带通道22 mm宽、2.4 mm高，适配约20 mm宽绑带；倒圆/打磨接触边并加薄防滑垫。148-78=70 mm为纯几何行程，装配时在端部各留至少5 mm给出线/软垫，建议可用行程约60 mm。电池应沿纵向移动，双绑带同时紧固；扎带或魔术贴不纳入打印材料质量。

主翼25%弦位置Z=-40 mm可作最初配平测量参考，不是已经确认的合适重心或中性点。先称重逐项计算：Zcg=Σ(mi×Zi)/Σmi，Ycg也须核验。每移动电池10 mm，整机重心改变10×电池质量/整机质量 mm。电池能否覆盖所需重心取决于实际质量、线材和图传选择，当前没有保证。

## 连接与装配顺序

1. 先做电机孔、飞塔孔、翼根嵌件孔和绑带通道小样，核对实物与打印公差。所有主结构均为PLA/ABS打印；螺钉、嵌件、垫片、软隔振件为购买件。
2. 翼根11 mm实心区内有两处Ø4.2、深8 mm嵌件导孔，Z=-45/-95。按实际M3热熔嵌件外径调整小样，插入深度不能穿破翼型皮。由电池仓内侧穿过中心框Ø3.4孔拧入翼根，使用大外径垫片分散载荷。先安装机翼后装电池；两螺栓相距50 mm用于抵抗弦向扭矩。
3. 左右每侧上、下支撑的曲面鞍座贴合机翼，四处X=138/152、Z=-48/-88的Ø3.4孔（左侧X取负）用贯穿螺栓、垫片和防松螺母夹紧。翼内孔周为实心柱并与外皮相接；不要把螺母压入薄翼皮。
4. 电机座目前采用一体支撑。四颗电机孔暂定16×16；不是所有2306.5电机都能直接安装。下方约35 mm结构会影响螺钉工具通路，应按实物确定长螺钉/工具长度，进入电机的有效螺纹长度严格按电机厂商要求。若孔距不同，修改并重印该支撑件。
5. 电子托板在中心框下方，用4处M3孔和约1 mm隔片连接；孔位X=±22、Z=-85/-40。飞塔向负Y安装，使用实际减震胶圈和绝缘柱，使元件不接触框架。
6. 图传适配板以40×32 mm四孔固定在电子托板，留约2 mm隔片；天空端位于板外侧，底部和侧边保持通风。相机座和可选云台板共用X=±10、Z=11的20 mm双孔接口，二选一安装。
7. 电子托板尾部预留两个Ø6.4孔，用于天线胶套或扎带固定，不是特定天线接头的压配孔。天线和导线须固定在桨盘之外，禁止悬垂到桨盘。

紧固件长度由实际堆叠厚度、垫片与螺纹啮合深度确定，不提供未经实物核验的统一长度。机翼与支撑鞍座理论零间隙贴合；不要强压翘曲件，应打磨结合面或按试样增加装配间隙。

## 图传、相机与云台兼容

|件号|用途|
|---|---|
|07|O4 Pro：25.5×25.5 mm，Ø2.3过孔用于M2|
|08|O4普通版：25.5×25.5 mm，Ø2.8软安装导孔；按原厂胶钉/胶圈复核|
|09|模拟图传20×20 mm、M2接口；其他尺寸模拟图传需另做板，不声称兼容全部模拟设备|
|10|相机通用26 mm净宽开口座，槽位穿窄扎带/绑带并配软垫固定|
|12/13/14|14.4、19.4、20.4 mm净宽减径衬块，分别供O4及常见模拟相机/机身参考；依实物选用|
|11|单轴云台预留板：24×13 mm舵机壳窗口，32 mm耳孔距Ø2.4；仅是可替换接口，不含完整运动机构|

DJI官方图纸中O4模块30×30×6，O4 Pro模块33.5×33.5×13；两者安装方式不同。预留位置兼容的是上述包络与适配接口，实际USB、SD卡、同轴线弯曲半径和相机防振仍需实物装配复核。当前相机采用夹持+绑带方案，没有猜测侧面螺纹孔位。短机身将相机和图传靠近布置，但不能从两点直线距离推断同轴线足够长。

用户允许外露散热，因此采用开放托板。DJI手册建议机内通风安装并避免意外触碰，本结构仍需通过实测确认散热与防触碰；PLA不能直接紧贴热源。热源与打印件之间使用隔片/软安装，使散热面保持空气流通。ABS也不是散热器，不得用塑料包住散热片。

## 分件打印

文件名带`_print.stl`的文件已摆放至Z=0；STEP保留装配坐标。不要打印LAYOUT中的电池、电机和桨盘包络。左右支撑有独立镜像文件，按件号各打印一件。07/08/09和10/11是配置替代件，非全部同时安装。

最大单件主尺寸188 mm，所有底面长宽均不超过186×174.5 mm范围（具体见geometry_report.json），适配256×256板并留足裙边空间。翼件以展向竖直打印，高188 mm；支撑侧放，凸出的电机座/鞍座需要局部支撑；中心框需在横桥及悬空平台下布置局部支撑。切片后必须逐层检查闭合皮、梁、肋及孔周，STL包络合格不代表已完成可打印性验证。

初始建议0.4 mm喷嘴、0.2 mm层高，翼皮按0.4 mm线宽尝试2道连续线；实体根部与电机座可用局部高填充，桁架4道壁起步。实际壁厚随翼型位置变化，薄后缘可能被切片器简化，应检查而不是强行指定零填充。ABS使用封闭环境并按耗材要求设置；PLA与ABS分别打印连接小样，不能套用同一个收缩补偿。

## 重量、强度和控制验证

CAD实体体积按PLA 1.24 g/cm³估算已安装打印结构约543 g，ABS按1.04约456 g；不是切片或称重结果。电子、电池、电机、桨、金属件、绑带和胶水另计。举例：若总重1.05 kg，外露翼面积0.05264 m²、假定CL=0.6、海平面密度1.225，所需平飞速度约23.1 m/s；这个示例不是失速速度预测，CL未获试验验证。

结构路径：电机座→带斜撑侧桁架→四孔鞍座→孔周实心柱/双翼梁→实心翼根→两颗嵌件螺栓→中央框。已明确受力路径并加厚接口，但FDM的层间强度、热蠕变、嵌件拔出和振动不能凭CAD确认。

使用前必须取得：实际总重和重心范围；最低工作电压下的单电机/整机推力、电流、温升；翼根弯曲、支撑扭转和嵌件拉拔实测；带桨前的无桨混控方向检查。载荷试验值应依据实测最大推力和目标机动载荷制定，当前没有完成结构验收。

30.5孔距飞塔不等于尾座飞控能力。ArduPilot的无舵面CopterMotor tailsitter要求前飞期间继续由所有电机提供控制；需确认具体飞控板的固件目标、混控、反扭矩方向、传感器和转换逻辑。不能直接沿用普通穿越机的自稳模式/PID，也不能把预留云台舵机当作飞行控制通道。

## 来源与交付性质

- DJI尺寸/安装：[O4系列用户手册](https://dl.djicdn.com/downloads/DJI_O4_Air_Unit_Series/UM/DJI_O4_Air_Unit_Series_User_Manual_v1.0_en.pdf)，第6页尺寸及第8页安装建议。
- 控制架构：[ArduPilot Tailsitter Planes](https://ardupilot.org/plane/docs/guide-tailsitter.html)。
- 参数实体源：上级目录build_h440.py。SolidWorks由STEP导入，原生保存文件中的实体属于导入特征，不是手工重建的完整草图/拉伸参数树。

未确认项：电池尺寸重量、电机底孔与底部/出线尺寸、飞塔型号与实际外廓、模拟设备型号、云台舵机型号。收到这些数据后需调整对应接口并再次做干涉与质量检查。

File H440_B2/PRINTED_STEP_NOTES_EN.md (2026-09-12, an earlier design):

# H440 B2 Printed STEP Delivery Notes

`H440_B2_printed_parts_STEP.zip` contains 18 printable CAD masters: 14 `P*.step` fittings/equipment mounts and four `W*.step` PLA wing sections.

- W01–W04: PLA wing sections.
- P02–P05: ABS spar collars, motor clevises and tail shoes.
- P06L/P06R: DJI O4 Pro camera brackets with an M2 pivot and 0–90° locking slot.
- P07: standard O4 Pro air-unit adapter.
- P08–P14: alternative O4, analog-video, gimbal-interface and generic-camera parts. Select only the parts required by the actual configuration.

STEP is the geometry master. `_print.stl` files provide suggested orientation only. Inspect slicer previews for minimum walls, supports, hole compensation and ABS shrinkage.

The O4 Pro brackets have 20.4 mm nominal internal clearance. Make a fit coupon before printing the complete set. Use thin washers under the M2 slot fasteners, and keep camera-thread engagement within 2 mm.

Use `SHA256SUMS.txt` in the archive to verify transfer integrity.

P01 angles are removed. P04 now has four clamp holes and a 4.15 mm slot; fit hard shims to the 4 mm pylon. P05 accepts 4 mm stock. Wing segmentation clearance is 4.4 mm. Do not mix B1 parts.

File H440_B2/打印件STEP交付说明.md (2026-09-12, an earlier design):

# H440 B2 打印件 STEP 交付说明

本包包含当前 B2 版本的全部打印件 CAD 主模型，共 18 个 STEP 文件：14 个 `P*.step` 连接件/设备安装件，以及 4 个 `W*.step` PLA 机翼分段。

- `W01`～`W04`：PLA 打印机翼。
- `P02`～`P05`：ABS 碳管套、电机转接座和尾撑脚套。
- `P06L/P06R`：DJI O4 Pro 可调相机左右侧板，采用 M2 枢轴孔和 0～90° 圆弧锁紧槽。
- `P07`：标准配置的 O4 Pro 天空端安装板。
- `P08`～`P14`：O4、模拟图传、云台接口及通用相机替代件；按实际配置选择，不能全部同时安装。

STEP 是打印件的 CAD 主模型；同目录 `_print.stl` 仅用于给出建议打印朝向。切片前应检查喷嘴线宽、最小壁厚、孔补偿、ABS 收缩和支撑。O4 Pro 两侧板的名义内净宽为 20.4 mm，首次打印建议先做局部试装，并按机器实际收缩率补偿。

相机侧螺钉使用 M2，并通过薄垫片压紧圆弧槽。DJI 规定相机螺纹最大旋入深度为 2 mm，应按侧板、垫片和螺钉头实际尺寸选螺钉长度。

`SHA256SUMS.txt` 用于核对文件传输完整性。

P01角码已取消。P04为四孔加强U座，夹槽4.15mm，装配4mm机臂时用硬质垫片消除间隙。P05脚套适配4mm侧板，翼分段间隔已调整至4.4mm，禁止与B1旧件混装。

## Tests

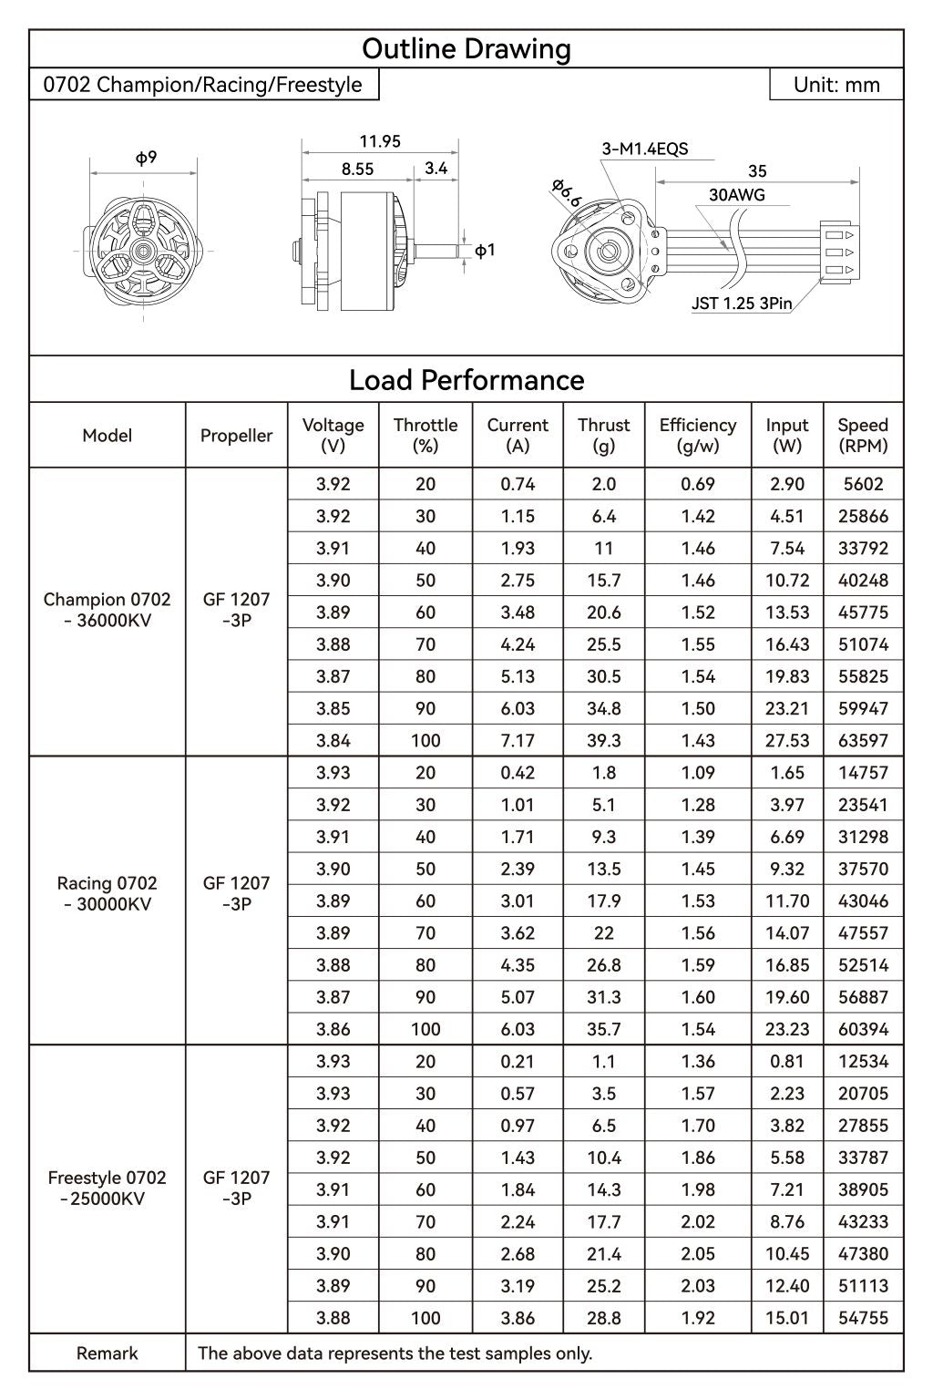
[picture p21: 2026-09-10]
reference/motor_performance.jpg

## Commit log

2026-09-10 Complete H440 B1 O4 Pro manufacturing delivery
    [Battery_bracket_-54_-1.SLDPRT, Battery_bracket_-54_1.SLDPRT, Battery_bracket_0_-1.SLDPRT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]
2026-09-10 Archive B1 manufacturing release with bilingual docs
    Add Chinese and English project guides with renders, verified CFRP and printed-part delivery archives, SolidWorks save updates, and repeatable archive verification tools.
    [P06R_O4Pro_camera_side.SLDPRT]
2026-09-12 Add B2 open battery tray and reinforced motor pylons
    Replace center angles with bonded mortises, remove the battery cage, add 4 mm cross-braced pylons and four-bolt ribbed clevises. Include checked STEP/DXF exports, bilingual notes, renders, BOM and comparative beam screening. Native B2 SolidWorks save/reopen remains pending due to desktop automation failure.
    [C01_center_side_R_2mm.step, C01_center_side_R_2mm_cut_mm.dxf, C02_center_side_L_2mm.step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]
2026-09-12 Complete B2 native SolidWorks delivery
    [Battery_floor.SLDPRT, C01_center_side_R_2mm.SLDPRT, C02_center_side_L_2mm.SLDPRT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]
2026-09-13 Clarify B2 native assembly verification
    [H440_B2_FRAME.SLDASM]
2026-09-13 Add B3 center lock and TPU camera support
    Add positively retained center decks with four metal spacer tie-bolts, dual-ended 5 mm TPU O4 Pro camera supports, camera/battery clearance updates, B3 manufacturing exports, verified SolidWorks native files, archive checks, renders, BOM and bilingual delivery notes.
    [Battery_floor.SLDPRT, C01_center_side_R_2mm.SLDPRT, C01_center_side_R_2mm.step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]
